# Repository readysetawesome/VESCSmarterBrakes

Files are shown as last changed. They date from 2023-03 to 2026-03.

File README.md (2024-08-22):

# VESCSmarterBrakes


a COMM or CAN based connection is used to intelligently illuminate brakes in a continuous/bright mode when reverse current (regen) is applied

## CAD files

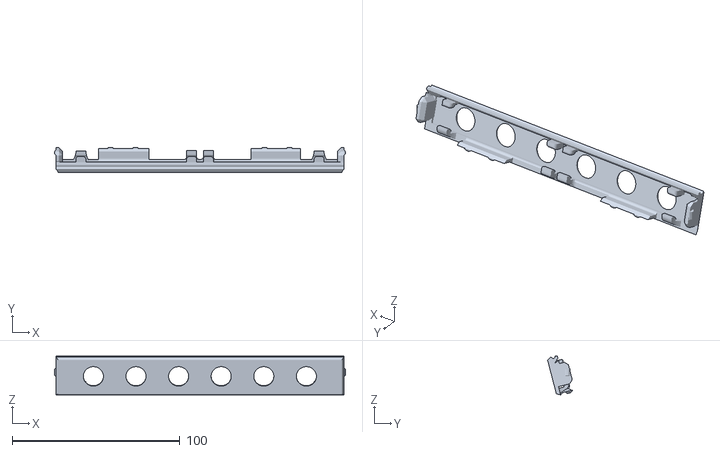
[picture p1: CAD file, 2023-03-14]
enclosure cover (translucent).stl
173.5 x 14.8 x 23.2

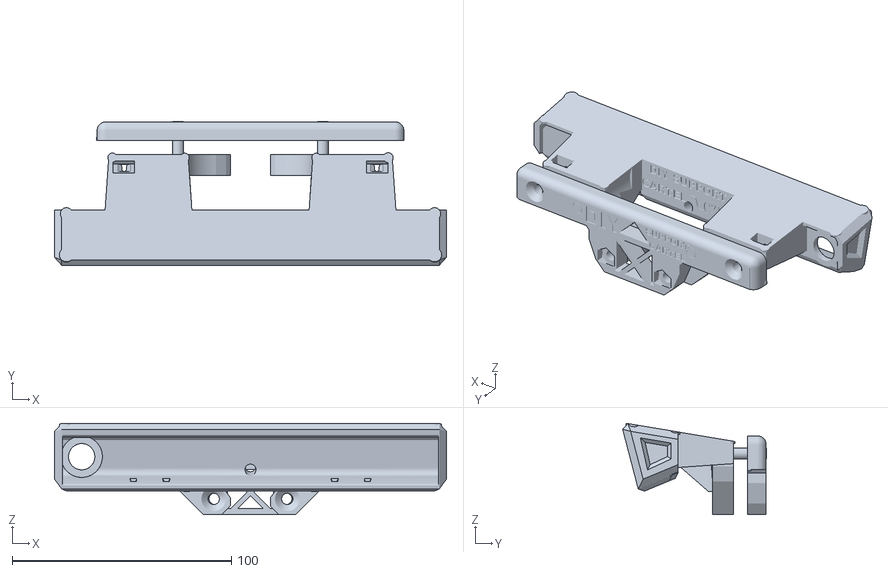
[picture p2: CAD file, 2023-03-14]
new Bolt pattern v31.stl
178.9 x 65.6 x 41.7

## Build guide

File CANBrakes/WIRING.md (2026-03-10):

# CANBrakes Wiring

## Components

| Part | Details |
|---|---|
| CAN module | Longan Labs Serial CAN Bus Module v1.3 (Aug 2020) — SKU 1030001 |
| MCU | ATmega168PA @ 16 MHz (YXC 16OSDF external crystal) |
| CAN controller | MCP2515, CS = pin 9 |
| CAN transceiver | MCP2551 |
| LED driver | LuxDrive MiniPuck F004-D-P-350, 350 mA constant current, high-high PWM mode |
| Dimmer signal diode | 1N4148 (signal diode, anode toward Arduino, cathode toward MiniPuck) |
| CAN termination | P1 solder pad bridged (adds onboard 120 Ω termination resistor) |

## Pin Assignments

| Pin | Grove label | Function |
|-----|---|---|
| 0 | RX | SoftPWM dimmer output → MiniPuck PWM input |
| 1 | TX | Mode button input (INPUT_PULLUP, active LOW) |
| 3 | — | Onboard status LED (active HIGH) |
| 9 | — | MCP2515 SPI chip select (internal, not broken out) |

## Wiring Diagram

```
  12V supply ──────────────────────────────────── MiniPuck Vin (+)
  GND ─────────────────────────────────────────── MiniPuck GND (−)
                                                   MiniPuck OUT+ ── LED strip +
                                                   MiniPuck OUT− ── LED strip −

  Arduino pin 0 ──[ 1N4148 ]──────────────────── MiniPuck PWM input
                    anode→   cathode→
  Arduino GND ─────────────────────────────────── MiniPuck GND
  12V GND ─────────────────────────────────────── MiniPuck GND (all grounds must share a common node)

  Mode button ── Arduino pin 1 (one side)
  GND ─────────── Arduino pin 1 (other side)   ← internal pull-up, press = LOW

  VESC CAN H ── CAN module CAN H
  VESC CAN L ── CAN module CAN L
```

## Key Notes

- **MiniPuck high-high mode**: PWM input HIGH = full brightness, LOW = off. The 1N4148
  drops ~0.7 V, so the Arduino's 5 V HIGH arrives as ~4.3 V — still a solid HIGH.
  The diode prevents the MiniPuck's 12 V-referenced circuitry from backfeeding into
  the Arduino's 5 V GPIO.

- **SoftPWM inversion**: `VESCSmarterBrakes` calls `SoftPWMSet(pin, 255 - value)` because
  the internal brightness constants use 0 = full on, 255 = off. The inversion maps that
  back to SoftPWM's 0 = off, 255 = full on convention.

- **CAN termination**: The bus needs 120 Ω at each end. Bridge the P1 solder pad on the
  CAN module to enable the onboard resistor. The VESC has its own termination built in.

- **CAN baud rate**: 500 kbps (VESC default). Set in `CANBrakes.ino` as `CAN_500KBPS`.

- **Multi-VESC**: `vesc_can.h` accepts Status frames from any controller ID on the bus.
  Brakes activate if any motor reports negative current (regen braking).

- **Programming**: FTDI adapter via Grove connector (TX→RX, RX→TX, GND, 5 V).
  No DTR on Grove — manually press RESET on the board when "Uploading..." appears.

## Sources

- [Longan Labs Serial CAN Bus Module v1.3 schematic & firmware](https://github.com/Longan-Labs/Serial_CAN_Bus_Module)
- [LuxDrive MiniPuck F004-D-P-350 datasheet](https://www.ledsupply.com/content/pdf/luxdrive-minipuck-datasheet.pdf)
- [SoftPWM library (bhagman)](https://github.com/bhagman/SoftPWM)
- [mcp_can library (coryjfowler)](https://github.com/coryjfowler/MCP_CAN_lib)
- [VESC CAN protocol — bldc source](https://github.com/vedderb/bldc/blob/master/comm/comm_can.c)

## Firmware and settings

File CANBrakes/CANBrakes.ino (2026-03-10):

#include <SoftPWM_timer.h>
#include <SoftPWM.h>
#include <SPI.h>
#include <mcp_can.h>
#include <VESCSmarterBrakes.h>
#include "vesc_can.h"

// ── Pin assignments ─────────────────────────────────────────────────────────
// CS pin confirmed from board firmware source (cmdMode.cpp: MCP_CAN CAN(9))
#define CAN_CS_PIN  9

// Grove connector pins repurposed as GPIO (hardware UART no longer used)
#define DIMMER_PIN  1    // TX connector pin → dimmer output via SoftPWM
#define BUTTON_PIN  0    // RX connector pin → mode button input

#define LED_PIN     3    // Onboard status LED (active HIGH)

// ── Objects ─────────────────────────────────────────────────────────────────
MCP_CAN CAN(CAN_CS_PIN);
// true = use SoftPWM, required because pins 0/1 have no hardware PWM
VESCSmarterBrakes Brakes(DIMMER_PIN, BUTTON_PIN, true);

// Default inpVoltage to a safe value so low-voltage protection
// doesn't fire before the first Status 5 frame arrives.
VescCanData vescData = {0, 0.0f, 48.0f};

void setup() {
    // Optiboot leaves UART enabled (RXEN0/TXEN0 set in UCSR0B), which overrides
    // GPIO function on pins 0 and 1. Disable UART before using those pins.
    UCSR0B = 0;

    pinMode(LED_PIN, OUTPUT);

    // Init CAN at 500 kbps — standard VESC CAN rate.
    while (CAN.begin(MCP_ANY, CAN_500KBPS, MCP_16MHZ) != CAN_OK) {
        delay(200);
    }
    CAN.setMode(MCP_NORMAL);
    digitalWrite(LED_PIN, LOW);   // LED off = CAN init OK, waiting for VESC data

    // SoftPWM must be initialised before Brakes.TurnOn() calls SetDimmerPower()
    SoftPWMBegin();
    // SoftPWM frequency set to 120Hz in SoftPWM.cpp (SOFTPWM_FREQ 120UL).
    // Default 60Hz was visibly flickery; 120Hz is above threshold with acceptable overhead.

    Brakes.TurnOn();
}

void loop() {
    bool newData = false;

    if (CAN.checkReceive() == CAN_MSGAVAIL) {
        unsigned long id;
        unsigned char len = 0;
        unsigned char buf[8];
        CAN.readMsgBuf(&id, &len, buf);
        newData = parseVescFrame(id, buf, vescData);
        if (newData) digitalWrite(LED_PIN, HIGH);
    }

    Brakes.DoLoop(vescData.rpm, vescData.avgMotorCurrent, vescData.inpVoltage, newData);
}

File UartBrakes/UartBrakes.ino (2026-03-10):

#include <VescUart.h>
#include <VESCSmarterBrakes.h>

// Dimmer pin, mode button pin
VESCSmarterBrakes Brakes(3, 9);
VescUart UART;

void setup() {
  #if defined(__AVR_ATmega32U4__) || defined(__AVR_ATmega16U4__)
  Serial1.begin(115200);
  UART.setSerialPort(&Serial1);
  #elif defined(__AVR_ATmega328P__)
  Serial.begin(115200);
  UART.setSerialPort(&Serial);
  #endif

  Brakes.TurnOn();
}

void loop() {
  static unsigned long lastQuery = 0;
  bool newData = false;

  if (millis() - lastQuery >= 15) {
    lastQuery = millis();
    if (UART.getVescValues()) {
      newData = true;
    }
  }

  Brakes.DoLoop(UART.data.rpm, UART.data.avgMotorCurrent, UART.data.inpVoltage, newData);
}

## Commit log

2021-01-03 add initial reorganized prototype code
2021-01-03 fix variable types, handle debounce better, handle mode transitions better
    [VESCSmarterBrakes.cpp]
2021-01-03 clarify some variable names, use 'currentPower' to store the run mode power
2024-08-22 Fix workflow build action (#2)
    * fix workflow errors
    [UartBrakes.ino, VESCSmarterBrakes.cpp]
2024-08-22 Add status badge 😁 (#3)
2024-08-22 Perform builds for both itsybitsy and pro mini (#5)
    * use fqbn to specify the adafruit list of boards
    * set up compile switches for board support
    * Fix job name for workflow builds
    [UartBrakes.ino]
2026-03-10 CAN bus brake light support (Longan Labs Serial CAN Module) (#6)
    * Initial commit: UART version baseline
    * Add CAN bus firmware for Longan Labs Serial CAN Bus Module
    Replaces UART VESC telemetry with CAN bus reception via the board's
    internal MCP2515 (CS pin 9, 16MHz crystal). Repurposes the Grove
    connector's RX/TX pins as dimmer output (SoftPWM) and button input.
    Core braking control loop is unchanged from the UART version.
    * Refactor: single canonical class, proxy cpp files eliminate duplication
    VescUart polling moved into UartBrakes.ino; DoLoop now accepts
    (rpm, current, voltage, newData) from the sketch layer. Both sketch
    fol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
    [CANBrakes.ino, UartBrakes.ino, VESCSmarterBrakes.cpp]
